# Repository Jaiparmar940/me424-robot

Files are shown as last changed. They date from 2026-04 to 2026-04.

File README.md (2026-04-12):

# ME424 Robot — Multi-Board ESP32 Firmware

Firmware for a 5-DOF robotic arm with an interchangeable tool head system. Three ESP32 dev boards communicate over UART to coordinate stepper motors, limit switches, and tool attachments (electromagnet, vacuum, circular saw, linear probe, etc.).

The wrist uses an 8-pin magnetic connector to hot-swap tools.

## System Architecture

```
┌──────────────┐   UART2    ┌──────────────┐
│              │ ──────────▸│              │
│  Main Board  │            │ MOSFET Board │   (tool power switching)
│              │◂────────── │              │
│              │   115200   └──────────────┘
│              │
│  - Wi‑Fi     │   UART1    ┌──────────────┐
│  - Steppers  │ ──────────▸│              │
│  - Commands  │            │ Sensor Board │   (limit switches, tool ID)
│              │◂────────── │              │
└──────────────┘   115200   └──────────────┘
```

| Board | Role |
|---|---|
| **Main Board** | Master controller. USB serial, Wi‑Fi (HTTP UI + WebSocket + OTA), drives 6 stepper motors via TB6600 drivers, routes commands to other boards over UART. |
| **MOSFET Board** | Receives commands from Main Board over UART. Drives 3 MOSFET outputs for electromagnet, vacuum, and circular saw. Sends ACK responses. |
| **Sensor Board** | Reads three limit switches plus Stage 5 Hall-at-zero (GPIO14 / HW-477) and reports state changes to Main Board over UART. |

## Project Structure

```
ME424_Robot/
├── platformio.ini              Multi-environment build config
├── src/
│   ├── main_board/main.cpp     Main board firmware
│   ├── mosfet_board/main.cpp   MOSFET slave board firmware
│   └── sensor_board/main.cpp   Sensor board firmware
├── include/                    Shared headers (empty, for future use)
├── lib/                        Shared libraries (empty, for future use)
└── .gitignore
```

---

## Pin Assignments

### Main Board

#### Stepper Motor Outputs (to TB6600 drivers)

| Controller | Stage Mapping | STEP Pin | DIR Pin | Direction Inverted |
|---|---|---|---|---|
| 1 | Stage 2 Right | GPIO 25 | GPIO 13 | No |
| 2 | Stage 3 | GPIO 33 | GPIO 14 | No |
| 3 | Stage 4 | GPIO 32 | GPIO 22 | No |
| 4 | Stage 2 Left | GPIO 27 | GPIO 21 | **Yes** |
| 5 | Stage 5 | GPIO 26 | GPIO 23 | No |
| 6 | Stage 1 (turntable) | GPIO 4 | GPIO 15 | No |

Stage 2 uses two motors (controllers 1 and 4) driven in sync. Controller 4 has its direction inverted so both motors move the same physical direction.

#### UART Connections

| Bus | Function | Main Board Pin | Remote Board Pin | Baud |
|---|---|---|---|---|
| UART2 | To MOSFET board | RX = GPIO 16, TX = GPIO 17 | MOSFET RX = GPIO 25, TX = GPIO 26 | 115200 |
| UART1 | To Sensor board | RX = GPIO 18, TX = GPIO 19 | Sensor TX = GPIO 27, RX = GPIO 26 | 115200 |
| UART0 | USB Serial (debug) | Default (GPIO 1 / 3) | — | 115200 |

#### Other

| Function | Details |
|---|---|
| Wi‑Fi | Station mode: OTA updates, HTTP dashboard on port 80, WebSocket commands on 81, optional TCP 3333 |

---

### MOSFET Board

GPIO **18** and **19** are the usual **MOSFET-switched** loads (mag, vac). GPIO **22** is different: it is a **small-signal / PWM line into an external BLDC driver module** (ESC or similar), not a discrete power MOSFET driven directly like 18/19. GPIO **23** enables saw **power** ahead of that driver.

| Function | GPIO | Mode | Notes |
|---|---|---|---|
| Electromagnet output | 18 | OUTPUT | Active HIGH → MOSFET (or equivalent) |
| Vacuum output | 19 | OUTPUT | Active HIGH → MOSFET (or equivalent) |
| Saw power / enable | 23 | OUTPUT | Active HIGH — supply or enable path to the BLDC driver |
| BLDC driver speed input | 22 | LEDC ~5 kHz | PWM duty 0–100% via `SAW SPEED` (driver module input; only while `SAW ON`) |
| UART RX (from Main TX) | 25 | UART1 RX | Cross-wired to Main GPIO 17 |
| UART TX (to Main RX) | 26 | UART1 TX | Cross-wired to Main GPIO 16 |
| USB Serial (debug) | Default | UART0 | 115200 baud |

All outputs default to LOW (off) on boot. The board sends `SLAVE READY` to the main board on startup.

---

### Sensor Board

| Function | GPIO | Mode | Notes |
|---|---|---|---|
| Stage 2 Limit Switch | 33 | INPUT_PULLUP | Active LOW (switch wired to GND) |
| Stage 3 Limit Switch | 32 | INPUT_PULLUP | Active LOW |
| Stage 4 Limit Switch | 25 | INPUT_PULLUP | Active LOW |
| UART TX (to Main RX) | 27 | UART1 TX | Cross-wired to Main GPIO 18 |
| UART RX (from Main TX) | 26 | UART1 RX | Cross-wired to Main GPIO 19 |
| USB Serial (debug) | Default | UART0 | 115200 baud |

---

## UART Wiring Diagram

```
Main Board                    MOSFET Board
──────────                    ────────────
GPIO 16 (RX2)  ◂──────────  GPIO 26 (TX1)
GPIO 17 (TX2)  ──────────▸  GPIO 25 (RX1)
GND            ──────────── GND

Main Board                    Sensor Board
──────────                    ────────────
GPIO 18 (RX1)  ◂──────────  GPIO 27 (TX1)
GPIO 19 (TX1)  ──────────▸  GPIO 26 (RX1)
GND            ──────────── GND
```

All UART buses run at **115200 baud, 8N1**.

---

## Command Reference

Commands are sent to the Main Board over **USB serial**, **WebSocket** (same line protocol as serial), or **TCP 3333**. Each command is case-insensitive and terminated by a newline (`\n`). Responses are echoed to USB and any active network clients.

### Stage Commands

| Command | Description |
|---|---|
| `s1cw <steps>` | Stage 1 (turntable) clockwise |
| `s1ccw <steps>` | Stage 1 (turntable) counter-clockwise |
| `s2up <steps>` | Stage 2 up (controllers 1 + 4 in sync, forward) |
| `s2down <steps>` | Stage 2 down (controllers 1 + 4 in sync, reverse) |
| `s3up <steps>` | Stage 3 up |
| `s3down <steps>` | Stage 3 down |
| `s4up <steps>` | Stage 4 up |
| `s4down <steps>` | Stage 4 down |
| `s5cw <steps>` | Stage 5 clockwise |
| `s5ccw <steps>` | Stage 5 counter-clockwise |

### Raw Controller Commands

| Command | Description |
|---|---|
| `c1f <steps>` / `c1r <steps>` | Controller 1 forward / reverse (Stage 2 Right) |
| `c2f <steps>` / `c2r <steps>` | Controller 2 forward / reverse (Stage 3) |
| `c3f <steps>` / `c3r <steps>` | Controller 3 forward / reverse (Stage 4) |
| `c4f <steps>` / `c4r <steps>` | Controller 4 forward / reverse (Stage 2 Left) |
| `c5f <steps>` / `c5r <steps>` | Controller 5 forward / reverse (Stage 5) |
| `c6f <steps>` / `c6r <steps>` | Controller 6 forward / reverse (Stage 1 / turntable) |

### MOSFET / Tool Commands

These are forwarded from the Main Board to the MOSFET Board over UART.

| Command | Forwarded As | MOSFET Board Response |
|---|---|---|
| `mag on` / `mag off` | `MAG ON` / `MAG OFF` | `ACK MAG ON` / `ACK MAG OFF` |
| `vac on` / `vac off` | `VAC ON` / `VAC OFF` | `ACK VAC ON` / `ACK VAC OFF` |
| `saw on` / `saw off` | `SAW ON` / `SAW OFF` | `ACK SAW ON` / `ACK SAW OFF` |
| `saw speed <0–100>` | `SAW SPEED <n>` | `ACK SAW SPEED <n>` — PWM on MOSFET **GPIO 22** while saw is on |
| `alloff` | `ALL OFF` | `ACK ALL OFF` |
| `mstatus` | `STATUS` | `STATUS … SAW_SPD=<0–100> …` |

### Sequence Commands

Commands are separated by `,`. Whitespace around commas is ignored.

| Command | Description |
|---|---|
| `seq <cmd1>, <cmd2>, ...` | Execute commands one at a time in order. Any command type is valid (motor, MOSFET, utility). |
| `par <cmd1>, <cmd2>, ...` | Execute motor commands simultaneously. All specified motors are stepped on the same clock tick. Motor/stage commands only — MOSFET commands are not supported in `par`. |
| `syncabs t1 t2 t3 t4 t5 t6 maxSps rampSteps` | Execute a synchronized **absolute** 6-axis move. Each axis reaches its target at the same time, speed is capped by `maxSps` (steps/s), and accel/decel ramping is applied using `rampSteps`. |
| `vertical [maxSps] [ramp]` | Same as the web **Go to vertical** button: `syncabs` to the stored vertical pose (defaults **1200** / **150**). Targets live in firmware as `kAppVerticalPose` — keep in sync with `VERTICAL_POSE` in `app.js`. |
| `autohome [maxSps] [ramp]` | Same as the web **Lift autohome** button: full lift calibration, ending at vertical then `setpos` all zeros. Optional `maxSps` / `ramp` override defaults **1200** / **150**. Constants match `LIFT_ROUTINE` in `app.js`. |
| `qclear` | Clear onboard queue |
| `qadd pose t1 t2 t3 t4 t5 t6 maxSps rampSteps` | Append a synchronized absolute move segment to onboard queue |
| `qadd delay ms` | Append delay segment to onboard queue |
| `qadd cmd <firmware command>` | Append command segment (e.g. `vac on`, `alloff`) |
| `qlist` | Print current queue items |
| `qrun` | Execute queued items on firmware (true onboard playlist execution) |
| `qstop` | Request stop for running queue |
| `qstatus` | Print queue count and stop state |

**Examples:**
```
seq s2up 400, s3down 200, mag on
par s2up 400, s5cw 200
par s3down 200, s4down 300, s1cw 100
seq par s3down 400, s4down 400, s2up 200, mag on
syncabs 0 1000 -500 0 200 0 1200 300
qclear
qadd pose 0 400 0 0 0 0 900 150
qadd delay 500
qadd cmd vac on
qadd pose 0 0 0 0 0 0 900 150
qadd cmd vac off
qrun
```

In `par`, motors with different step counts run until each individually finishes — longer moves continue while shorter ones stop. Limits are checked per-motor on every step.

### Utility Commands

| Command | Description |
|---|---|
| `speed <us>` | Set stepper pulse delay in microseconds (minimum 100) |
| `where` | Print the tracked current position for all 6 controllers |
| `setpos p1 p2 p3 p4 p5 p6` | Overwrite the tracked position state (useful after manual zeroing/homing) |
| `estop` | Latch emergency stop immediately (also during active motion/queue). Motion commands are blocked until cleared. Also sends `ALL OFF` to MOSFET board. |
| `estop clear` | Clear the e-stop latch to allow motion again |
| `estop status` | Print `ESTOP=1` or `ESTOP=0` |
| `limits` | Print last-known limit switch and Stage 5 Hall (`S5H`) states |
| `home s1` | Jog turntable (C6) in the + direction (`c6f` / `s1cw`) until the S1 CW limit is active, then set C6 to 0. Uses a **slower** step pulse during the seek than global `speed` (≈2× delay, capped) so the table homes gently. |
| `home s2` | Drive Stage 2 toward its limit, then zero C1/C4 at the limit |
| `home s3` | Drive Stage 3 toward its limit, then zero C2 |
| `home s4` | Drive Stage 4 toward its limit, then zero C3 |
| `home s5` | Jog Stage 5 until Hall at zero (`S5H=0`), then zero C5 |
| `home s1 bounce` … `home s4 bounce` | Same as `home sN` but: fast approach, back off 260 steps, slow final creep, then zero. **S1 (turntable)** uses **slower** fast/slow pulse scaling than S2–S4 (see firmware `homeS1Bounce*PulseUs`). Stage 5 has no bounce variant. |
| `help` | Print command menu |

---

## Limit Switch Safety

The sensor board monitors three limit switches plus a Stage 5 Hall line (3144-style sensor through an HW-477 comparator on **GPIO14**; homing-only, not a motion limit) and sends state changes to the main board using this protocol:

```
LIM S2=1 S3=0 S4=0 S5H=0
```

For **S2–S4**, `1` = limit switch triggered (pressed), `0` = open. For **S5H** the convention is reversed: **`0` = at Hall zero position**, `1` = away from zero. Adjust the HW-477 threshold pot. Sensor firmware defaults to **`S5_HALL_AT_ZERO_ACTIVE_HIGH = false`** (pin **LOW** = at zero); set to `true` if your comparator output is the opposite.

### Behavior

The main board uses direction-aware limit logic. Limits only block motion in the **downward** direction for a given stage — upward motion is always allowed even if the limit is triggered. The sensor UART is polled mid-step so limits are checked during long moves and will halt motion immediately.

If a limit is already active when a command is received, the command is rejected with an `ABORT` message. If a limit triggers mid-move, the motors stop and a `STOP` message is sent.

### Direction Mapping

| Stage | "Down" Direction | Limit Blocks |
|---|---|---|
| Stage 1 | — | No limit switch |
| Stage 2 | `s2down` (forward = false) | Downward motion only |
| Stage 3 | `s3down` (forward = true) | Downward motion only |
| Stage 4 | `s4down` (forward = true) | Downward motion only |
| Stage 5 | — | No limit switch (Hall `S5H` on sensor board is for **homing only**, not blocking motion) |

### Limit-to-Motor Mapping

| Limit Switch | Motors Affected |
|---|---|
| Stage 2 | Controllers 1 + 4 (stopped together) |
| Stage 3 | Controller 2 |
| Stage 4 | Controller 3 |

---

## Wi‑Fi usage (replaces Bluetooth)

Bluetooth Classic has been removed to save flash/RAM. Use one of the following:

| Channel | Purpose |
|---|---|
| USB serial | 115200 baud, same as before |
| Browser | Open `http://me424-main.local/` (or the main board IP) for the hosted web app; it connects over WebSocket port 81 |
| TCP | `nc me424-main.local 3333` for raw line commands |
| OTA | PlatformIO `*_ota` environments upload firmware over the network |

### Serial terminal settings (USB)

| Setting | Value |
|---|---|
| Baud rate | 115200 |
| Data bits | 8 |
| Parity | None |
| Stop bits | 1 |
| Line ending | Newline (`\n`) |

---

## Tool Connector (8-Pin Magnetic)

The wrist connector carries power and signals to interchangeable tools:

| Pin(s) | Function | Direction | Notes |
|---|---|---|---|
| 1, 2 | V+ (tool power) | Arm -> Tool | Paralleled for current capacity |
| 3, 4 | GND | — | Paralleled |
| 5 | BLDC PWM control | Arm -> Tool | PWM signal to on-tool motor driver |
| 6 | BLDC enable / digital control | Arm -> Tool | Enable line |
| 7 | ADC signal (shared) | Tool -> Arm | Probe potentiometer OR tool ID resistor |
| 8 | Spare | — | Reserved for future use |

### Tool Identification

Each tool contains a resistor to GND on pin 7. The arm has a fixed pull-up resistor to 3.3V on the same pin, forming a voltage divider read by the sensor board's ADC. Different resistance values identify different tools.

```
3.3V ── [fixed R on board] ──┬── ADC pin (GPIO on sensor board)
                              │
                    [tool R] ── GND (through connector)
```

> Tool ID and ADC reading are not yet implemented in firmware.

---

## Building and Uploading

### Prerequisites

- [PlatformIO IDE extension](https://platformio.org/install/ide?install=vscode) installed in VS Code / Cursor
- ESP32 USB drivers installed (CP2102 or CH340 depending on your dev board)

### Using the PlatformIO IDE (recommended)

1. Open the `ME424_Robot` folder in Cursor/VS Code.
2. PlatformIO will auto-detect `platformio.ini` and index the project.
3. Use the PlatformIO sidebar or the bottom toolbar:
   - Click the **environment switcher** in the status bar to select `main_board`, `mosfet_board`, or `sensor_board`.
   - Click **Build** (checkmark icon) to compile.
   - Click **Upload** (arrow icon) to flash the selected board.
   - Click **Serial Monitor** (plug icon) to open the monitor at 115200 baud.

### Using the PlatformIO CLI

```bash
# Build a specific board
pio run -e main_board
pio run -e mosfet_board
pio run -e sensor_board

# Upload to a specific board (auto-detects USB port)
pio run -e main_board -t upload
pio run -e mosfet_board -t upload
pio run -e sensor_board -t upload

# Upload to a specific USB port
pio run -e main_board -t upload --upload-port /dev/cu.usbserial-0001

# Open serial monitor
pio device monitor -e main_board

# Build all environments
pio run

# Clean build artifacts
pio run -t clean
```

### WiFi / OTA Upload (All Boards)

Bluetooth transport on the main board has been replaced with WiFi command + OTA support.  
All three boards now support Arduino OTA when WiFi credentials are compiled in.

1. Set WiFi credentials in `platformio.ini` under `[env]` (`build_flags`: `WIFI_SSID`, `WIFI_PASSWORD`). Each board env merges these via `${env.build_flags}`.
2. First flash each board once over USB:

```bash
pio run -e main_board -t upload
pio run -e mosfet_board -t upload
pio run -e sensor_board -t upload
```

3. Then use OTA environments:

```bash
pio run -e main_board_ota -t upload
pio run -e mosfet_board_ota -t upload
pio run -e sensor_board_ota -t upload
```

Default OTA hostnames are:
- `me424-main.local`
- `me424-mosfet.local`
- `me424-sensor.local`

### Wireless web app (main board)

The main board serves the dashboard from **LittleFS** at **`http://<ip>/`** (try `http://me424-main.local/`). The same UI talks to the firmware over **WebSocket** port **81** (line-based commands, same as USB serial). Raw TCP on port **3333** still works for `nc` / scripts.

After changing files in `app/`, copy them into `data/` and upload the filesystem (USB or OTA):

```bash
cp app/index.html app/app.js app/styles.css data/
pio run -e main_board -t uploadfs
# or, after OTA works:
pio run -e main_board_ota -t uploadfs
```

Open the UI in a browser on the same Wi‑Fi network; the page auto-connects over Web‑Fi. Use `http://localhost:8080/app/` (or similar) with **Connect (USB Serial)** for local dev, or add **`?usb=1`** to the robot URL to force USB from a desktop.

### Setting Upload Ports

If you have multiple ESP32 boards connected simultaneously, uncomment and set the `upload_port` lines in `platformio.ini`:

```ini
[env:main_board]
build_src_filter = -<*> +<main_board/>
upload_port = /dev/cu.usbserial-0001

[env:mosfet_board]
build_src_filter = -<*> +<mosfet_board/>
upload_port = /dev/cu.usbserial-0002

[env:sensor_board]
build_src_filter = -<*> +<sensor_board/>
upload_port = /dev/cu.usbserial-0003
```

To find your port names:

```bash
# macOS / Linux
ls /dev/cu.usb*

# Windows (in PlatformIO terminal)
pio device list
```

### Upload Order

There is no strict order, but a practical sequence is:

1. **Sensor board** — starts reporting limits immediately on boot
2. **MOSFET board** — starts listening for commands, all outputs default off
3. **Main board** — expects the other two boards to already be running

---

## Web App (8 Requirements UI)

A browser app is included at `app/` and uses Web Serial to talk directly to the main ESP.

### Run the App

1. Start a local static server from repo root:
   - `python3 -m http.server 8080`
2. Open [http://localhost:8080/app/](http://localhost:8080/app/)
3. Click **Connect (Web Serial)** and select your ESP32 serial port.

Use Chrome or Edge desktop (Web Serial is not supported in Safari/Firefox).

### Requirement Coverage

1. **Manual jog with granularity**
   - `Manual Control` section
   - Set `Step Size`
   - Use `+ Jog` / `- Jog` per motor

2. **Record all 6 positions in one state**
   - `Record Current Pose` captures all 6 tracked positions

3. **Add delays between states**
   - Set `Delay (ms)` and click `Add Delay`

4. **Append more recorded positions**
   - Record additional poses; list appends in order

5. **Toggle MOSFET functions in same list**
   - Choose `MOSFET Action`, click `Add MOSFET Action`

6. **Replay with synchronized finish + ramps + max speed**
   - Sequence playback uses firmware command:
     - `syncabs t1 t2 t3 t4 t5 t6 maxSps rampSteps`
   - `Playback maxSps` and `Playback rampSteps` control speed/ramp
   - Axis motion is synchronized so all active axes finish together

7. **Zero / home from buttons**
   - `Set Current as Zero (All)` → soft-zero all tracked positions (`setpos …`)
   - `Zero This Axis` on each axis → soft-zero that controller only
   - `Auto home (home sN)` under each stage → runs the matching firmware homing command (`home s1` … `home s5`)
   - `Home Stages 2–4 (limits)` → runs `home s2`, then `home s3`, then `home s4` in order

8. **Save commands locally**
   - `Save Local` / `Load Local` uses browser `localStorage`
   - `Export JSON` / `Import JSON` for file-based reuse

### App Data Model

Sequence items are one of:
- `pose`: six-axis absolute positions
- `delay`: milliseconds
- `mosfet`: command string (`mag on`, `vac off`, etc.)

---

## Inter-Board Protocols

### Sensor Board (Sensor <-> Main)

#### Messages Sent (Sensor -> Main)

| Message | Meaning |
|---|---|
| `SENSOR READY` | Boot complete |
| `LIM S2=<0\|1> S3=<0\|1> S4=<0\|1> S5H=<0\|1>` | S2–S4: `1` = limit hit; **S5H: `0` = at Hall zero**, `1` = away (sent on change and at boot) |
| `ERR UNKNOWN_CMD` | Unrecognized command received |

#### Commands Accepted (Main -> Sensor)

| Command | Response |
|---|---|
| `STATUS` | Sends current `LIM ...` message |

### MOSFET Board (MOSFET <-> Main)

#### Messages Sent (MOSFET -> Main)

| Message | Meaning |
|---|---|
| `SLAVE READY` | Boot complete |
| `ACK MAG ON` / `ACK MAG OFF` | Electromagnet toggled |
| `ACK VAC ON` / `ACK VAC OFF` | Vacuum toggled |
| `ACK SAW ON` / `ACK SAW OFF` | Saw toggled |
| `ACK ALL OFF` | All outputs turned off |
| `STATUS … SAW_SPD=<0–100> …` | Current outputs + saw PWM setpoint |
| `ERR UNKNOWN_CMD` | Unrecognized command received |

#### Commands Accepted (Main -> MOSFET)

| Command | Response |
|---|---|
| `MAG ON` / `MAG OFF` | `ACK MAG ON` / `ACK MAG OFF` |
| `VAC ON` / `VAC OFF` | `ACK VAC ON` / `ACK VAC OFF` |
| `SAW ON` / `SAW OFF` | `ACK SAW ON` / `ACK SAW OFF` |
| `ALL OFF` | `ACK ALL OFF` |
| `STATUS` | `STATUS MAG=... VAC=... SAW=... SAW_SPD=... TOOL_R=...` |

---

## Future Work

- [ ] Add tool identification via ADC voltage divider on the sensor board
- [ ] Add linear probe (potentiometer) reading
- [ ] Add debouncing / filtering to limit switch reads
- [ ] Add shared protocol header in `lib/` for message definitions

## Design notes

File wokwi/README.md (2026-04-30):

# ME424 Wokwi Circuit Model

This folder contains a Wokwi-importable visual wiring model for your control circuit:

- `diagram.json`

## What this model includes

- Main ESP32 (`main`) and Sensor ESP32 (`sensor`)
- UART link between boards (GPIO19/18 pair represented via UART1 TX/RX symbols)
- Sensor limit inputs:
  - Stage 1 CW limit -> GPIO13
  - Stage 2 limit -> GPIO33
  - Stage 3 limit -> GPIO32
  - Stage 4 limit -> GPIO25
  - Stage 5 Hall input -> GPIO14
- Tool outputs on sensor board:
  - MAG -> GPIO18
  - VAC -> GPIO19
  - SAW MOSFET gate -> GPIO21
  - SAW PWM -> GPIO22
- Tool ID / probe analog model:
  - ADC34 with 10k divider + tool resistor
  - ADC35 shown tied to a potentiometer signal
- Main board motor control indicators:
  - STEP pins: 25, 33, 32, 27, 26, 4
  - DIR pins: 13, 14, 22, 21, 23, 15

## Upload / open online

1. Go to [Wokwi ESP32 New Project](https://wokwi.com/projects/new/esp32).
2. Open `diagram.json` in this folder.
3. Copy all content and paste it into Wokwi's `diagram.json`.
4. Click **Save**.

## Notes

- This is a **visual/logic wiring model** for documentation and interaction testing.
- It is not an exact electrical model of TB6600 drivers, power rails, or saw power electronics.
- If you want, I can generate a second version with:
  - explicit virtual buttons for common commands,
  - a clearer grouped layout for screenshots,
  - or a dedicated variant matching `main_board_sensor_mosfet`.

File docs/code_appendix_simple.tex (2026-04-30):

% =====================================================
% ME424 Robot - SIMPLE TIGHT CODE APPENDIX
% =====================================================
% 
% Add to the VERY FIRST LINE of main.tex:
% \UseRawInputEncoding
% 
% Add to preamble:
% \usepackage{verbatim}
% \usepackage{xcolor}
% \usepackage{hyperref}
% 
% Usage:
% \input{code/docs/code_appendix_simple.tex}
% (or paste the content below directly into your appendix section)

\section*{Appendix: Complete Project Source Code}
\label{app:full-source}
\addcontentsline{toc}{section}{Appendix: Complete Project Source Code}

This appendix contains all custom project code with very tight formatting (\scriptsize font, minimal spacing). Only project-specific files are included.

\subsection*{Firmware - Main Board}

\textbf{File: \texttt{code/src/main\_board/main.cpp} (Primary implementation)}

\verbatiminput{code/src/main_board/main.cpp}

\textbf{File: \texttt{code/main\_board/main\_board.ino} (Legacy)}

\verbatiminput{code/main_board/main_board.ino}

\subsection*{Firmware - Sensor Board}

\textbf{File: \texttt{code/sensor\_board/sensor\_board.ino}}

\verbatiminput{code/sensor_board/sensor_board.ino}

\textbf{File: \texttt{code/src/sensor\_board/main.cpp}}

\verbatiminput{code/src/sensor_board/main.cpp}

\subsection*{Firmware - MOSFET/Tool Board}

\textbf{File: \texttt{code/src/mosfet\_board/main.cpp}}

\verbatiminput{code/src/mosfet_board/main.cpp}

\textbf{File: \texttt{code/mosfet\_board/mosfet\_board.ino}}

\verbatiminput{code/mosfet_board/mosfet_board.ino}

\subsection*{Web Interface}

\textbf{File: \texttt{code/app/app.js} (Main UI)}

\verbatiminput{code/app/app.js}

\textbf{File: \texttt{code/data/app.js}}

\verbatiminput{code/data/app.js}

\subsection*{Configuration \& Docs}

\textbf{File: \texttt{code/platformio.ini}}

\verbatiminput{code/platformio.ini}

\textbf{File: \texttt{code/README.md}}

\verbatiminput{code/README.md}

\textbf{File: \texttt{code/wokwi/diagram.json}}

\verbatiminput{code/wokwi/diagram.json}

\textbf{File: \texttt{code/docs/application_ui_subsection.tex}}

\verbatiminput{code/docs/application_ui_subsection.tex}

\subsection*{ROS/Python Support (Key Files)}

\textbf{File: \texttt{code/ros-py/serial_bridge.py}}

\verbatiminput{code/ros-py/serial_bridge.py}

\textbf{File: \texttt{code/ros-py/ros_src.py}}

\verbatiminput{code/ros-py/ros_src.py}

\subsection*{Pose Data Example}

\textbf{File: \texttt{code/poses/me424-homing.json}}

\verbatiminput{code/poses/me424-homing.json}

\vspace{0.5em}
\noindent \textbf{Note:} Very tight formatting with \scriptsize font and minimal spacing. If any file is not found, upload the `code/` folder structure to Overleaf or comment out the line with \%. 

To reference this appendix: `\ref{app:full-source}` or `\autoref{app:full-source}`.

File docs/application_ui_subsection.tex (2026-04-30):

\subsection{Application and User Interface Functionality}
\label{subsec:application-ui-functionality}

The ME424 robot application provides a browser-based operator interface that connects to the main controller over Wi-Fi and supports both low-level actuator control and higher-level task execution. At runtime, the firmware serves a web interface from onboard flash storage (LittleFS), accepts commands through WebSocket/TCP channels, and relays status from both the motion controller and the sensor/tool subsystem. This design gives users a single interface for motion, homing, tooling, safety control, and system diagnostics.

\subsubsection{Overall UI Structure and Operator Workflow}

The UI is organized to support a practical workflow:
\begin{enumerate}
  \item Connect to the robot over the network and confirm communication.
  \item Inspect robot state (positions, limits, and tool status).
  \item Home required stages to establish a known reference.
  \item Execute manual jog commands or synchronized/queued routines.
  \item Enable or disable end-effector tools as needed.
  \item Monitor acknowledgements, errors, and safety events in real time.
\end{enumerate}

In normal operation, the interface acts as a command console with structured controls, while the firmware enforces hardware safety constraints (limit blocking and e-stop latching) in the background.

\begin{figure}[htbp]
  \centering
  % Replace the file name with your screenshot path
  
  \caption{Main web UI overview, showing command controls, status panels, and live output.}
  \label{fig:ui-overview}
\end{figure}

\subsubsection{Connection, Session Feedback, and Live Communication}

When loaded in a browser, the UI establishes a live command/status channel to the main board (WebSocket on port 81, with TCP command support on port 3333). The interface should indicate connection state and then begin displaying streamed acknowledgements and state lines. Typical operator-visible feedback includes:
\begin{itemize}
  \item \texttt{ACK ...} messages confirming accepted commands,
  \item \texttt{DONE ...} messages when motions complete,
  \item \texttt{ERR ...} messages for malformed or invalid requests,
  \item limit and sensor reports relayed from the sensor board,
  \item emergency-stop state transitions (\texttt{ESTOP LATCHED/CLEARED}).
\end{itemize}

This continuous feedback loop is critical: users should interpret the UI as a command-and-confirm system rather than a fire-and-forget interface.

\begin{figure}[htbp]
  \centering
  
  \caption{Connection and live status area showing command acknowledgements and device responses.}
  \label{fig:ui-connection-status}
\end{figure}

\subsubsection{Manual Motion Controls and Direct Interaction}

The interface supports direct motion through stage-based controls and raw controller commands:
\begin{itemize}
  \item Stage commands (\texttt{s1cw}, \texttt{s2up}, \texttt{s3down}, etc.) provide semantically meaningful robot actions.
  \item Raw controller commands (\texttt{cXf}/\texttt{cXr}) expose per-driver step control for debugging and calibration.
  \item Adjustable speed/timing parameters allow users to tune responsiveness and smoothness.
\end{itemize}

User interaction is typically button-driven (for common motions) or text-command-driven (for advanced commands). The system validates step counts and rejects invalid values. During motion, the firmware monitors limits and e-stop state every cycle; if a stop condition is encountered, motion is aborted and the event is reported back to the UI.

\begin{figure}[htbp]
  \centering
  
  \caption{Manual motion controls for stage-level and controller-level movement commands.}
  \label{fig:ui-manual-motion}
\end{figure}

\subsubsection{Homing and Coordinate Management Features}

A key UI feature is guided homing and zero management. The operator can issue homing commands per stage:
\begin{itemize}
  \item Stage 1 homes to a clockwise limit reference.
  \item Stages 2--4 home to mechanical limit switches with direction-aware blocking.
  \item Stage 5 homes to a Hall-sensor zero region.
  \item Bounce homing modes improve repeatability by using a two-pass touch strategy.
\end{itemize}

The application also supports tracked position display (\texttt{where}), direct position overwrite (\texttt{setpos}), and persistent zero-step offsets by stage. This makes the UI suitable for both everyday operation and setup/recalibration sessions.

\begin{figure}[htbp]
  \centering
  
  \caption{Homing and position-management controls, including zeroing workflow and state readback.}
  \label{fig:ui-homing-position}
\end{figure}

\subsubsection{Sequencing, Queues, and Coordinated Task Execution}

Beyond manual control, the UI exposes multiple routine-execution mechanisms:
\begin{itemize}
  \item \textbf{Sequential execution} (\texttt{seq}): runs a comma-separated list of commands in order.
  \item \textbf{Parallel execution} (\texttt{par}): runs supported motor commands simultaneously.
  \item \textbf{Synchronized absolute motion} (\texttt{syncabs}): executes multi-axis targets with speed and ramp limits.
  \item \textbf{Queue manager}: supports \texttt{qadd pose}, \texttt{qadd delay}, \texttt{qadd cmd}, \texttt{qlist}, \texttt{qrun}, \texttt{qstop}, and \texttt{qclear}.
\end{itemize}

From a user perspective, this enables a progression from manual jogs to repeatable scripted workflows. The queue panel should be documented with expected operator steps: construct queue, verify items, execute, monitor logs, and stop/clear if needed.

\begin{figure}[htbp]
  \centering
  
  \caption{Queue and routine execution controls for repeatable multi-step operation.}
  \label{fig:ui-queue-routines}
\end{figure}

\subsubsection{Tooling Panel and End-Effector Interaction}

The UI includes dedicated controls for end-effector tooling:
\begin{itemize}
  \item magnet control (\texttt{MAG ON/OFF}),
  \item vacuum control (\texttt{VAC ON/OFF}),
  \item saw enable/disable (\texttt{SAW ON/OFF}),
  \item saw speed command (\texttt{SAW SPEED x}),
  \item global tool shutdown (\texttt{ALL OFF}),
  \item tool telemetry query (\texttt{MSTATUS}).
\end{itemize}

Returned tool telemetry includes actuator states, saw speed setpoint, identified tool resistor class, and compression/probe displacement estimate. This gives users immediate confirmation that the expected attachment is detected and that commanded tool states are active.

\begin{figure}[htbp]
  \centering
  
  \caption{Tooling controls and status readback for magnet, vacuum, and saw subsystems.}
  \label{fig:ui-tooling-panel}
\end{figure}

\subsubsection{Safety, Fault Handling, and Operator Responsibilities}

The UI exposes safety commands directly, but safety enforcement is implemented in firmware:
\begin{itemize}
  \item Emergency stop can be latched from serial or network sources.
  \item While latched, all commanded motion is blocked.
  \item Tool outputs are forced off on e-stop latch via \texttt{ALL OFF}.
  \item Limit-switch and Hall-derived states are continuously integrated into command blocking logic.
\end{itemize}

Recommended user interaction pattern:
\begin{enumerate}
  \item Before motion: check limit and e-stop status.
  \item During motion: watch live acknowledgements and stop on unexpected behavior.
  \item Before tool activation: verify tool identification/status panel.
  \item After operation: use \texttt{ALL OFF} and confirm final system state.
\end{enumerate}

\begin{figure}[htbp]
  \centering
  
  \caption{Safety and fault status region with e-stop state and limit feedback.}
  \label{fig:ui-safety-status}
\end{figure}

\subsubsection{How to Integrate This Section in a Report}

This file is intended to be included from a larger report using:
\begin{verbatim}
\input{docs/application_ui_subsection.tex}
\end{verbatim}

To compile successfully, ensure your preamble includes:
\begin{verbatim}
\usepackage{graphicx}
\end{verbatim}

Then add the corresponding screenshot image files under a directory such as \texttt{figures/}, matching the filenames used in the \texttt{\textbackslash includegraphics} commands.

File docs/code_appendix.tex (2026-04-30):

% =====================================================
% ME424 Robot Project - Complete Code Appendix (Overleaf - code/ folder)
% =====================================================
%
% **Your structure**: All folders are inside a top-level `code/` folder.
% Paths have been updated to `code/src/...`, `code/app/...`, etc.
%
% **Simplest option (recommended)**:
% 1. Copy-paste the content below (starting at \section*{Appendix...}) into your main report's appendix.
% 2. Ensure the `code/` folder exists in Overleaf with all the subfolders/files.
% 3. Add these packages to your main report preamble (near the top):
%      \usepackage[utf8]{inputenc}
%      \usepackage[T1]{fontenc}
%      \usepackage{listings}
%      \usepackage{xcolor}
%      \usepackage{hyperref}
%      \usepackage{array}   % fixes the "Illegal pream-token (L/C)" table errors
% 4. Recompile. The new settings should resolve the UTF-8, JavaScript, and math-mode errors.
%
% If you still get errors, reply with the new log — common fixes are ready.

\lstset{
  basicstyle=\ttfamily\scriptsize,
  keywordstyle=\color{blue}\bfseries,
  commentstyle=\color{green!60!black},
  stringstyle=\color{red!60!black},
  numberstyle=\tiny\color{gray!60},
  numbersep=4pt,
  backgroundcolor=\color{gray!8},
  frame=single,
  framesep=3pt,
  framerule=0.4pt,
  tabsize=2,
  breaklines=true,
  breakatwhitespace=true,
  postbreak=\mbox{\textcolor{red}{$\hookrightarrow$}\space},
  keepspaces=true,
  showspaces=false,
  showstringspaces=false,
  aboveskip=2pt,
  belowskip=2pt,
  xleftmargin=12pt,
  xrightmargin=6pt,
  columns=flexible,
  linewidth=0.98\linewidth,
  inputencoding=utf8,
  extendedchars=true,
  % Prevent UTF-8 and special character errors common in Arduino/JS code
  literate={�}{{\textquestiondown}}1 {–}{{-}}1 {’}{{'}}1 {“}{{"}}1 {”}{{"}}1,
  % Make JavaScript use C++ highlighting (more reliable in listings)
  language=C++
}

% Define additional languages
\lstdefinelanguage{PlatformIO}{
  morekeywords={platform,board,framework,env,build_flags,lib_deps,build_src_filter,upload_port,monitor_speed,upload_protocol,extends},
  sensitive=false,
  morecomment=[l]{;},
  morecomment=[l]{\#},
}

% For Markdown and JSON, listings falls back gracefully

\section*{Appendix: Complete Project Source Code}

\subsection*{Firmware - Main Board}
\textbf{File:} \texttt{src/main_board/main.cpp} (Primary implementation, \textasciitilde 4100 lines)

\lstinputlisting[language=C++,caption={Primary Main Board Firmware - code/src/main_board/main.cpp},label=lst:src-main-board]{code/src/main_board/main.cpp}

\textbf{File:} \texttt{code/main_board/main_board.ino} (Legacy version)

\lstinputlisting[language=C++,caption={Legacy Main Board - code/main_board/main_board.ino},label=lst:main-board-ino]{code/main_board/main_board.ino}

\subsection*{Firmware - Sensor Board}
\textbf{File:} \texttt{code/sensor_board/sensor_board.ino} (Primary sensor/tool firmware)

\lstinputlisting[language=C++,caption={Sensor Board Firmware - code/sensor_board/sensor_board.ino},label=lst:sensor-board]{code/sensor_board/sensor_board.ino}

\textbf{File:} \texttt{code/src/sensor_board/main.cpp} (PlatformIO version)

\lstinputlisting[language=C++,caption={PlatformIO Sensor Board - code/src/sensor_board/main.cpp},label=lst:src-sensor-board]{code/src/sensor_board/main.cpp}

\subsection*{Firmware - MOSFET/Tool Board}
\textbf{File:} \texttt{code/src/mosfet_board/main.cpp} 

\lstinputlisting[language=C++,caption={MOSFET Board Firmware - code/src/mosfet_board/main.cpp},label=lst:src-mosfet-board]{code/src/mosfet_board/main.cpp}

\textbf{File:} \texttt{code/mosfet_board/mosfet_board.ino} (Legacy)

\lstinputlisting[language=C++,caption={Legacy MOSFET Board - code/mosfet_board/mosfet_board.ino},label=lst:mosfet-board-ino]{code/mosfet_board/mosfet_board.ino}

\subsection*{Web Interface}
\textbf{File:} \texttt{code/app/app.js} (Main browser UI application, \textasciitilde 1565 lines - WebSocket, command UI, pose execution, etc.)

\lstinputlisting[language=C++,caption={Web UI - code/app/app.js},label=lst:app-js]{code/app/app.js}

\textbf{File:} \texttt{code/data/app.js} (Version served from LittleFS)

\lstinputlisting[language=C++,caption={Served UI - code/data/app.js},label=lst:data-app-js]{code/data/app.js}

\subsection*{Project Configuration}
\textbf{File:} \texttt{code/platformio.ini}

\lstinputlisting[language=PlatformIO,caption={PlatformIO Configuration},label=lst:platformio-ini]{code/platformio.ini}

\textbf{File:} \texttt{code/README.md}

\lstinputlisting[language=,caption={Project README.md},label=lst:readme]{code/README.md}

\subsection*{Simulation and Docs}
\textbf{File:} \texttt{code/wokwi/diagram.json} \& \texttt{code/wokwi/README.md}

\lstinputlisting[language=JSON,caption={Wokwi Diagram - code/wokwi/diagram.json},label=lst:wokwi-diagram]{code/wokwi/diagram.json}

\lstinputlisting[language=,caption={Wokwi README},label=lst:wokwi-readme]{code/wokwi/README.md}

\textbf{File:} \texttt{code/docs/application_ui_subsection.tex} (UI documentation subsection)

\lstinputlisting[language=TeX,caption={UI Documentation Subsection},label=lst:ui-subsection]{code/docs/application_ui_subsection.tex}

\subsection*{ROS/Python Support}
Key files from \texttt{ros-py/} (full directory contains additional bridge, IK, launch files; old/ directory has legacy code):

\lstinputlisting[language=Python,caption={Serial Bridge - code/ros-py/serial_bridge.py},label=lst:serial-bridge]{code/ros-py/serial_bridge.py}

\lstinputlisting[language=Python,caption={ROS Source - code/ros-py/ros_src.py},label=lst:ros-src]{code/ros-py/ros_src.py}

% Example of additional files (uncomment and adjust paths as needed):
% \lstinputlisting[language=Python,caption={RAMSES Robot Bridge},label=lst:ramses-bridge]{code/ros-py/ros_def/ramses_robot_bridge/ramses_robot_bridge/ramses_robot_bridge.py}

\subsection*{Pose Data (Example)}
Pose JSON files define motion sequences. Example shown; others follow similar format.

\lstinputlisting[language=JSON,caption={Example Pose - code/poses/me424-homing.json},label=lst:homing-json]{code/poses/me424-homing.json}

% Additional poses (me424-*.json, saw-*.json) can be added similarly if required for the report.

\vspace{1em}
\noindent \textbf{Note:} To generate a fully self-contained version with all code embedded (no \texttt{lstinputlisting}), or to include more ROS files / all poses, reply with specific instructions. The current setup prioritizes practicality for a printed report while satisfying the requirement of having all project code available in one LaTeX reference document. 

The modified \texttt{src/main_board/main.cpp} is fully captured above.

% End of appendix content. Do NOT include \end{document} if you \input this file into a larger report.

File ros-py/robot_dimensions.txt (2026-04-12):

Global Origin (0, 0, 0): at the center of the turntable (x, y), and the height of the the top surface of the docking station (z)
The axis pointing from the turntable out towards the docking station is the positive x-axis.

This means the attachment docking stations have the following coordinates, in inches:
   1. Probe: (9.515, 4.434, 0.0)
   2. Bonesaw: (10.5, 0.0, 0.0)
   3. Vaccuum: (9.515, -4.434, 0.0)

Regarding the links - Consider S1 through S5 as the joints of the robot arm, with S1 being the base joint and S5 being the end effector joint. The lengths of the links between these joints are as follows:
- L1 (between S1 and S2): 6.335 inches. Note that S2 will be at (0, 0, 6.335) always, since it is directly above S1, which rotates about the z-axis.
- L2 (between S2 and S3): 10.0 inches
- L3 (between S3 and S4): 8.0 inches
- L4 (between S4 and S5): 3.209 inches
- L5 (between S5 and the connector ending): 1.143 inch (the length to the connector - note that this distance is an extension of the L4 distance, and the significance is that the 'twist' along the L4/L5 link if at this point)
- L6 - this is essentially the link from the end of the connector to the tip of the end effectors. This will vary for each attachment, and will not always be centered on the end of the connector. Let's define a coordinate system for the end of the connector, with the z-axis pointing outwards from the connector, the x-axis pointing to the right of the connector, and the y-axis pointing upwards along the connector. Let the origin be that end of L5. The the L6 coordinates for each attachment are as follows:
   1. Probe: (0.0, 0.0, 5.350)
   2. Bonesaw: (0.0, 4.705, 2.197)
   3. Vaccuum: (0.0, 0.0, 2.635) 

For joint rotational limits (these need to be verified/calibrated, but are ballpark estimates):
- S1: -129 degree to 156 degrees (with 0 degrees being the position where the arm is pointing directly towards the docking station, and positive rotation being counterclockwise when looking down from above). The limit switch will be at the lower limit.
- S2: -94.16 degree to 86 degrees (with 0 degrees being the position where the arm is fully extended vertically upwards, and positive rotation being counterclockwise. So all stages are at their zero, decreasing S2 will lower the arm towards the +X axis) The limit switch will be at the lower limit.
- S3: -113 degree to 79.6 degrees (with 0 degrees being the position where the arm is straight vertical up when all stages are at their zero, and negative rotation will lower the arm towards the +X axis when all stages are zero). The limit switch will be at the lower limit.
- S4: -83 degree to 79 degrees (with 0 degrees being the position where the arm is straight vertical up when all stages are at their zero, and negative rotation will lower the arm towards the +X axis when all stages are zero). The limit switch will be at the lower limit.
- S5: -180 degrees to 180 degrees (with 0 degrees being the position where the end effector is in its default orientation, and positive rotation being counterclockwise when looking along the L4/L5 link from S4 towards S5). The limit is a hall effect at -180 degrees.

Stage steps pre revolution (with 16x microstepping):
- S1: 16640
- S2: 57600
- S3: 38400
- S4: 33600
- S5: 3200

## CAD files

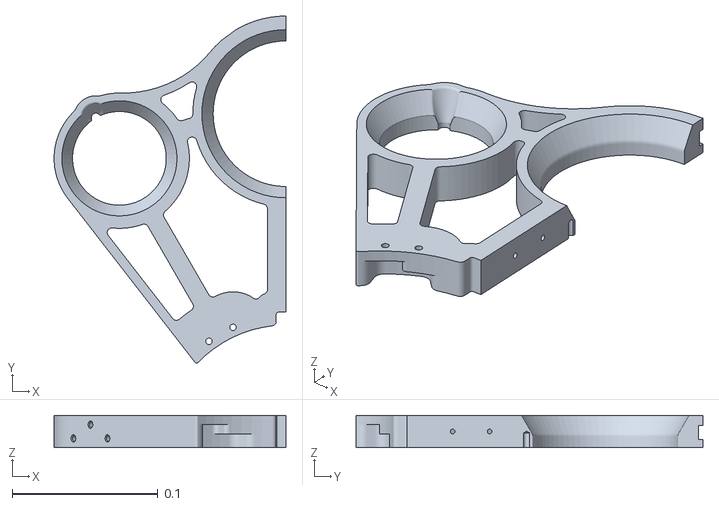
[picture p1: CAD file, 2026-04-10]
ros-py/ros_def/ramses_robot_description/meshes/ds_leftframe_002.stl
0.159 x 0.238 x 0.0222

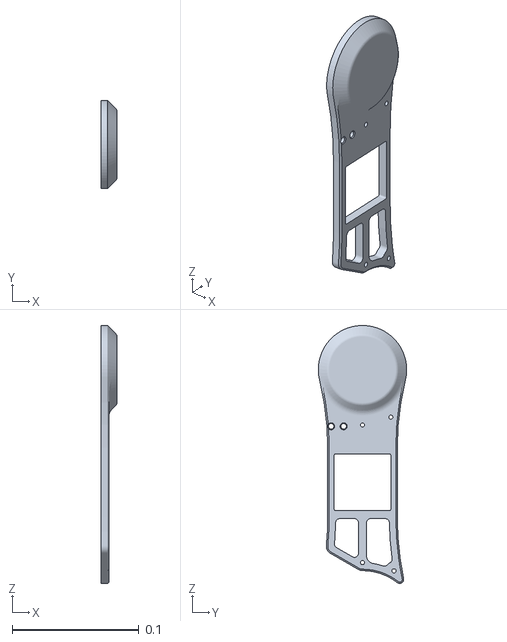
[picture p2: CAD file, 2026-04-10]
ros-py/ros_def/ramses_robot_description/meshes/s3_cover1_021.stl
0.0127 x 0.0698 x 0.204

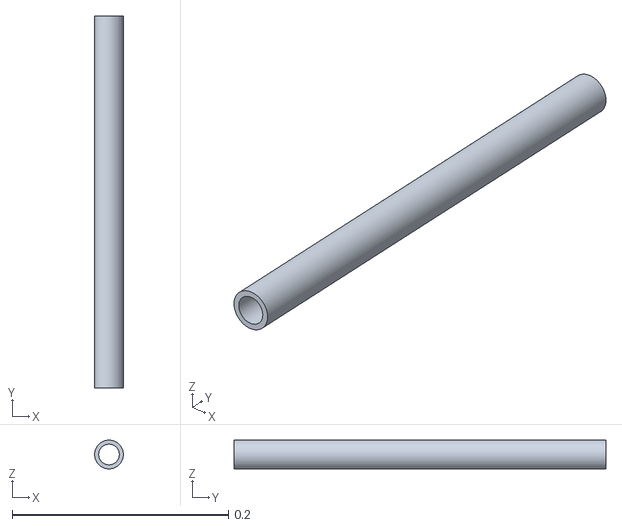
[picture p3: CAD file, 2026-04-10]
ros-py/ros_def/ramses_robot_description/meshes/tc_pvc_13_546.stl
0.0267 x 0.344 x 0.0267

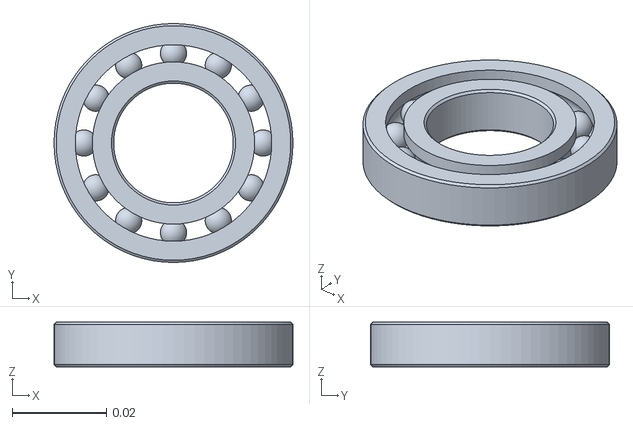
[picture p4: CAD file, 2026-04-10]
ros-py/ros_def/ramses_robot_description/meshes/composite_part_1__2.stl
0.0508 x 0.0508 x 0.00953

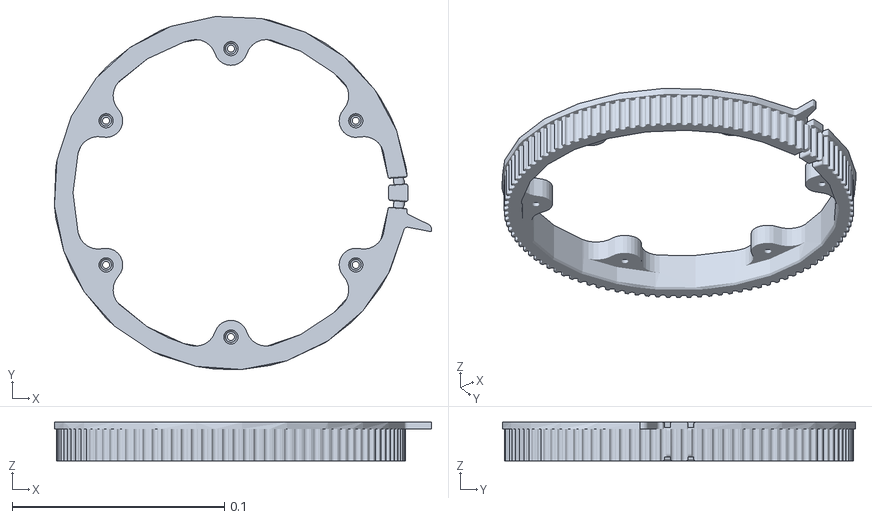
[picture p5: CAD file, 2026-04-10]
ros-py/ros_def/ramses_robot_description/meshes/104t_ringpulley.stl
0.178 x 0.166 x 0.0182

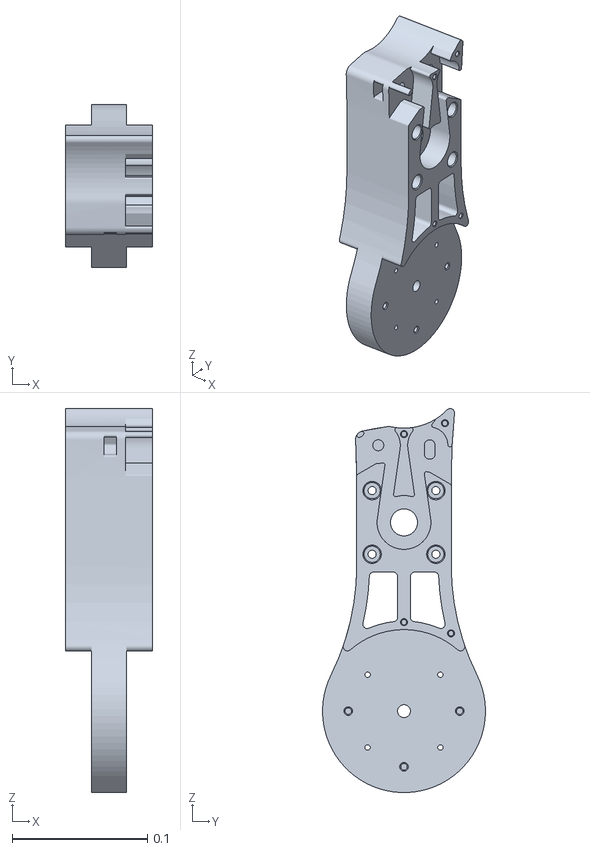
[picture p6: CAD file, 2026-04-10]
ros-py/ros_def/ramses_robot_description/meshes/part_7__2.stl
0.0643 x 0.121 x 0.284

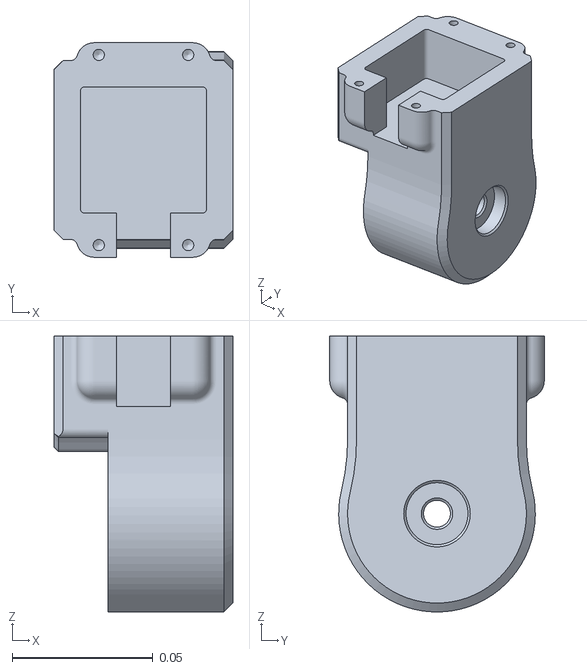
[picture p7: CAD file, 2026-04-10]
ros-py/ros_def/ramses_robot_description/meshes/s4_core_020.stl
0.0635 x 0.0762 x 0.098

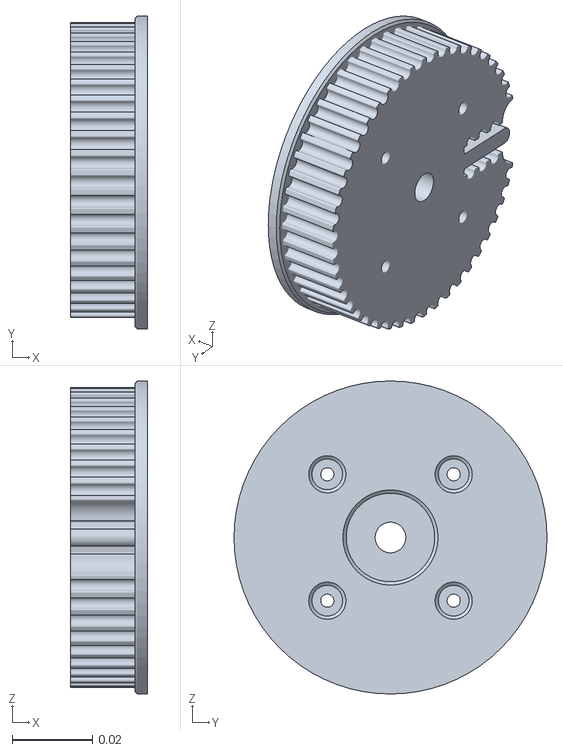
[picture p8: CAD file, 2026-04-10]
ros-py/ros_def/ramses_robot_description/meshes/48t_pulley.stl
0.0192 x 0.0779 x 0.0779

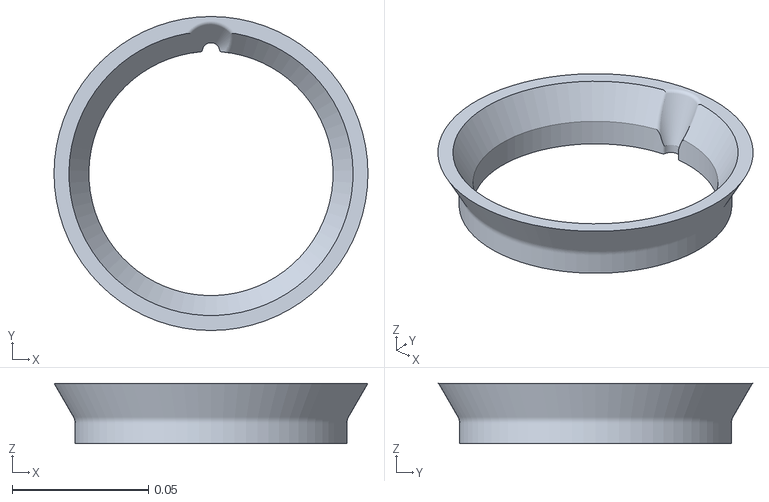
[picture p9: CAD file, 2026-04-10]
ros-py/ros_def/ramses_robot_description/meshes/ds_centraldockadapter_001.stl
0.115 x 0.115 x 0.0222

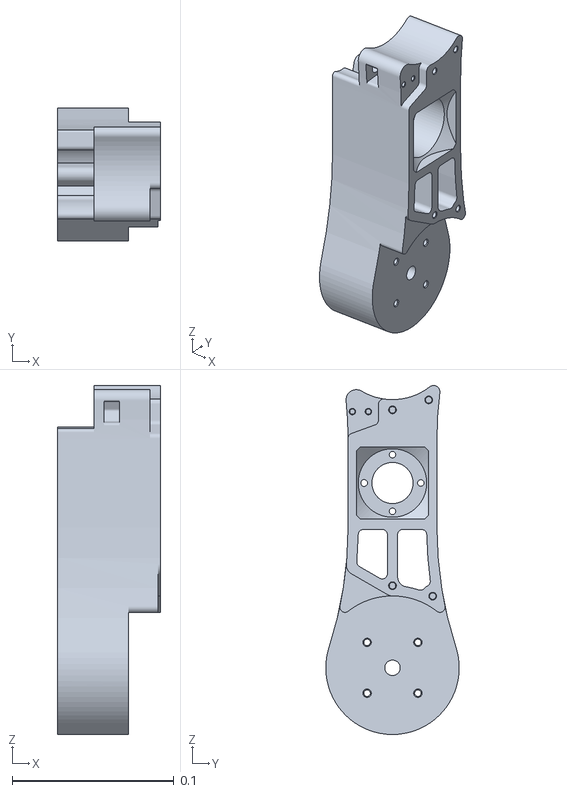
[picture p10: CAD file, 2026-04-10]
ros-py/ros_def/ramses_robot_description/meshes/s3_core_024.stl
0.0635 x 0.0825 x 0.216

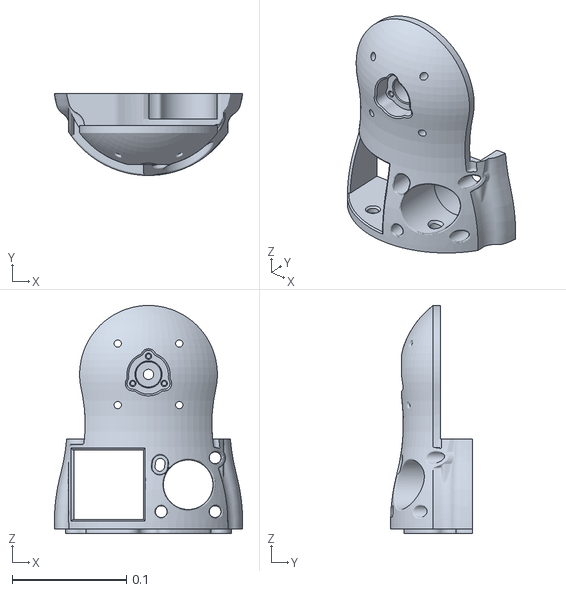
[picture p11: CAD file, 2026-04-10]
ros-py/ros_def/ramses_robot_description/meshes/s1_pile2_007.stl
0.165 x 0.0717 x 0.2

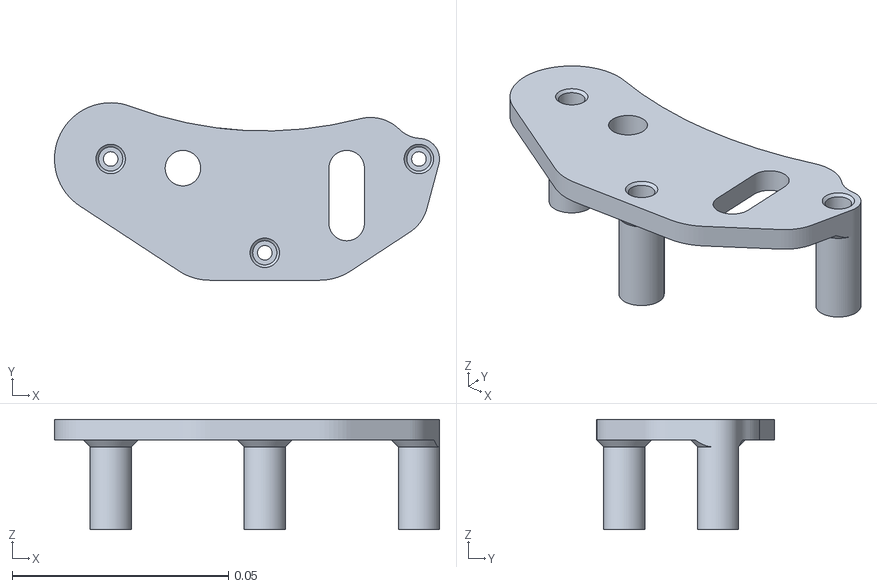
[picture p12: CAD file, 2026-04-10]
ros-py/ros_def/ramses_robot_description/meshes/b_tensionstandoff_011.stl
0.089 x 0.0411 x 0.0255

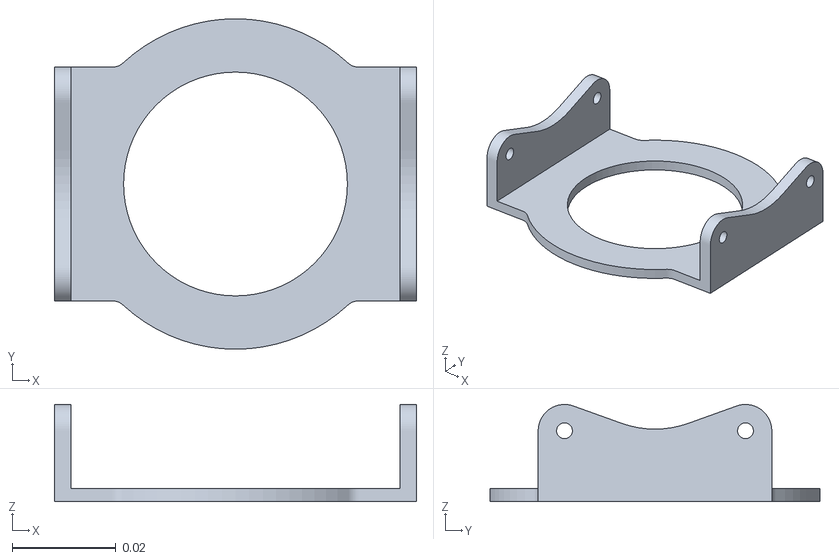
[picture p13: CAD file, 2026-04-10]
ros-py/ros_def/ramses_robot_description/meshes/part_2__2.stl
0.0698 x 0.0638 x 0.0187

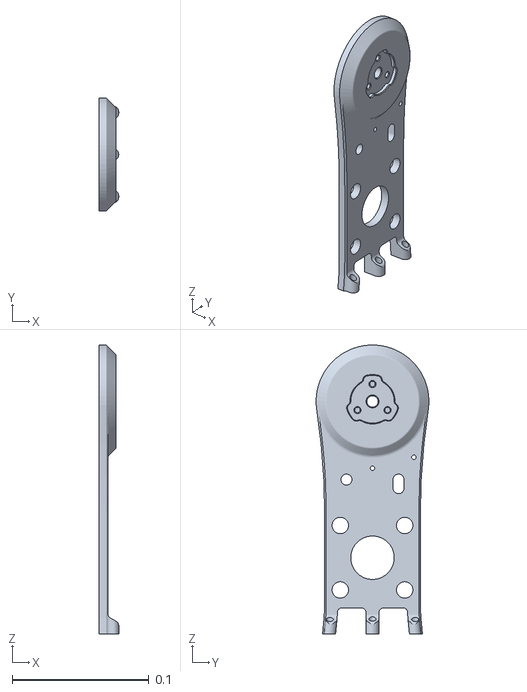
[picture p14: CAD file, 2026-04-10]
ros-py/ros_def/ramses_robot_description/meshes/part_11__2.stl
0.0143 x 0.0825 x 0.211

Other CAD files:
ros-py/ros_def/ramses_robot_description/meshes/ds_rightframe_003.stl
ros-py/ros_def/ramses_robot_description/meshes/nema17_5_1_gearbox.stl
ros-py/ros_def/ramses_robot_description/meshes/42t_pulley.stl
ros-py/ros_def/ramses_robot_description/meshes/90_fitting.stl
ros-py/ros_def/ramses_robot_description/meshes/b_limitmount_017.stl
ros-py/ros_def/ramses_robot_description/meshes/b_motorplate_010.stl
ros-py/ros_def/ramses_robot_description/meshes/b_pvcmount_012.stl
ros-py/ros_def/ramses_robot_description/meshes/b_turntablebase_001.stl
ros-py/ros_def/ramses_robot_description/meshes/hex_nut_grade_a___b_m8x1_25__3430b5bbd516b81b52e50f5ca3422a70.stl
ros-py/ros_def/ramses_robot_description/meshes/hex_socket_head_cap_screw_m8x1_25_x_25__a9f2d9bcc6cdc071be143b59fb9dc981.stl
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

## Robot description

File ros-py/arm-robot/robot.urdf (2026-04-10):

<?xml version="1.0" ?>
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
<robot name="C:\Users\conno\Documents\me424-robot\ros-py\arm-robot">

  <link name="world"/>

  <joint name="world_to_base" type="fixed">
    <parent link="world"/>
    <child link="b_turntablebase_001"/>
    <origin xyz="0 0 0" rpy="0 0 0"/>
  </joint>

  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
  <link name="b_turntablebase_001">
    <inertial>
      <origin xyz="8.72341e-05 0.0429888 0.00589545" rpy="0 0 0"/>
      <mass value="7.61097"/>
      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
    </inertial>
    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
  </link>
  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
  <link name="s1_bearingplug_003">
    <inertial>
      <origin xyz="-0.000130278 1.2507e-05 0.0992505" rpy="0 0 0"/>
      <mass value="1.95427"/>
      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
    </inertial>
    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
  </link>
  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
  <link name="nema23_2_0nm">
    <inertial>
      <origin xyz="0.000285325 -0.0920124 -0.0388436" rpy="0 0 0"/>
      <mass value="1.29278"/>
      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
    </inertial>
    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
  </link>
  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
  <link name="nema17_5_1_gearbox">
    <inertial>
      <origin xyz="-0.000154674 -0.0786034 -0.0285654" rpy="0 0 0"/>
      <mass value="0.798546"/>
      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
    </inertial>
    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
  </link>
  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
  <link name="s4_core_020">
    <inertial>
      <origin xyz="0.000773028 0.0242398 -0.0265345" rpy="0 0 0"/>
      <mass value="0.374744"/>
      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
    </inertial>
    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
  </link>
  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
  <link name="s5_armconnector_036">
    <inertial>
      <origin xyz="0.000375764 -5.61588e-07 -0.0133012" rpy="0 0 0"/>
      <mass value="0.0706859"/>
      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
    </inertial>
    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
  </link>
  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
  <joint name="s5_wrist_twist" type="revolute">
    <origin xyz="-0 0.0789686 -0.03175" rpy="1.5708 -0.536359 -0"/>
    <parent link="s4_core_020"/>
    <child link="s5_armconnector_036"/>
    <axis xyz="0 0 1"/>
    <limit effort="10" velocity="10" lower="-0.536359" upper="5.74683"/>
  </joint>
  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
  <joint name="s4_wrist" type="revolute">
    <origin xyz="-0 -0.2032 -0.0635" rpy="-3.14159 -0 0.687129"/>
    <parent link="nema17_5_1_gearbox"/>
    <child link="s4_core_020"/>
    <axis xyz="0 0 1"/>
    <limit effort="10" velocity="10" lower="-0.709134" upper="2.22302"/>
  </joint>
  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
  <joint name="s3_elbow" type="revolute">
    <origin xyz="0 -0.254 -0.0070104" rpy="-0 0 -1.87906"/>
    <parent link="nema23_2_0nm"/>
    <child link="nema17_5_1_gearbox"/>
    <axis xyz="0 0 1"/>
    <limit effort="10" velocity="10" lower="-0.0757129" upper="3.32768"/>
  </joint>
  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
  <joint name="s2_shoulder" type="revolute">
    <origin xyz="-0 -0.0385064 0.179503" rpy="-1.5708 -0.698555 -3.14159"/>
    <parent link="s1_bearingplug_003"/>
    <child link="nema23_2_0nm"/>
    <axis xyz="0 0 1"/>
    <limit effort="10" velocity="10" lower="-1.13404" upper="2.26935"/>
  </joint>
  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
  <joint name="s1_turntable" type="revolute">
    <origin xyz="-0 0 0.0036195" rpy="0 0 1.61412"/>
    <parent link="b_turntablebase_001"/>
    <child link="s1_bearingplug_003"/>
    <axis xyz="0 0 1"/>
    <limit effort="10" velocity="10" lower="-2.27734" upper="2.57467"/>
  </joint>
</robot>

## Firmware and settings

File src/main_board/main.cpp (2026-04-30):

#include <Arduino.h>
#include <cstring>
#include <WiFi.h>
#include <ArduinoOTA.h>
#include <FS.h>
#include <LittleFS.h>
#include <WebServer.h>
#include <WebSocketsServer.h>
#include <Preferences.h>

// Version 12.7

#ifndef WIFI_SSID
#define WIFI_SSID "surgical_clanker2.4"
#endif
#ifndef WIFI_PASSWORD
#define WIFI_PASSWORD "bone_saw"
#endif
#ifndef WIFI_HOSTNAME
#define WIFI_HOSTNAME "me424-main"
#endif

WiFiServer CommandServer(3333);
WiFiClient commandClient;

WebServer httpServer(80);
WebSocketsServer webSocket(81);
bool webSocketLive = false;

// Never call broadcastTXT from inside webSocketEvent (e.g. during handleCommand) — it drops clients.
// Queue lines here; wsTxFlush() runs after webSocket.loop().
// printHelp() alone is ~70 lines; keep headroom so WebSocket clients see the full list (e.g. "ip" under Other:).
#define WS_TX_QUEUE_DEPTH 160
static String wsTxQueue[WS_TX_QUEUE_DEPTH];
static uint8_t wsTxQueueLen = 0;

static void wsTxEnqueue(const String &line) {
  if (wsTxQueueLen >= WS_TX_QUEUE_DEPTH) {
    Serial.println(F("WS TX queue overflow (line dropped)"));
    return;
  }
  wsTxQueue[wsTxQueueLen++] = line;
}

static void wsTxFlush() {
  if (!webSocketLive || wsTxQueueLen == 0) return;
  for (uint8_t i = 0; i < wsTxQueueLen; i++) {
    webSocket.broadcastTXT(wsTxQueue[i]);
  }
  wsTxQueueLen = 0;
}
bool httpServerLive = false;

bool DEBUG = false;

// =========================
// Stepper config
// =========================
const int NUM_DRIVERS = 6;

const int STEP_PINS[NUM_DRIVERS] = {25, 33, 32, 27, 26, 4};
const int DIR_PINS[NUM_DRIVERS]  = {13, 14, 22, 21, 23, 15};

int pulseDelayUs = 1000;
long currentPos[NUM_DRIVERS] = {0, 0, 0, 0, 0, 0};
volatile bool estopLatched = false;
String estopSerialBuffer = "";
String estopWifiBuffer = "";

enum QueueItemType {
  Q_POSE = 0,
  Q_DELAY = 1,
  Q_CMD = 2
};

struct QueueItem {
  QueueItemType type;
  long targets[NUM_DRIVERS];
  long maxSps;
  int rampSteps;
  unsigned long delayMs;
  String cmd;
};

const int MAX_QUEUE_ITEMS = 64;
QueueItem runQueueItems[MAX_QUEUE_ITEMS];
int runQueueCount = 0;
bool queueStopRequested = false;

// Stage-to-controller mapping:
// Stage 1 = turntable          -> controller 6 (index 5)
// Stage 2 = base lift pair     -> controllers 1+4 (index 0+3)
// Stage 3 = arm segment        -> controller 2 (index 1)
// Stage 4 = arm segment        -> controller 3 (index 2)
// Stage 5 = wrist              -> controller 5 (index 4)

const int STAGE1       = 5;   // controller 6
const int STAGE2_RIGHT = 0;   // controller 1
const int STAGE3       = 1;   // controller 2
const int STAGE4       = 2;   // controller 3
const int STAGE2_LEFT  = 3;   // controller 4
const int STAGE5       = 4;   // controller 5

const int NUM_STAGES = 5;
/** Per-stage zero step offset: logical = raw + offset(stage). S2 applies to both lift motors (C1+C4). Persisted as zs0..zs4. */
long zeroStepOffsetByStage[NUM_STAGES] = {0, 0, 0, 0, 0};

static long zeroOffsetForDriver(int driverIdx) {
  if (driverIdx == STAGE1) return zeroStepOffsetByStage[0];
  if (driverIdx == STAGE2_RIGHT || driverIdx == STAGE2_LEFT) return zeroStepOffsetByStage[1];
  if (driverIdx == STAGE3) return zeroStepOffsetByStage[2];
  if (driverIdx == STAGE4) return zeroStepOffsetByStage[3];
  if (driverIdx == STAGE5) return zeroStepOffsetByStage[4];
  return 0;
}

void enforceStage2PairTarget(long targets[NUM_DRIVERS]) {
  // Stage 2 must always remain paired (controllers 1 and 4).
  // Use C1 as the authoritative value when both are provided.
  targets[STAGE2_LEFT] = targets[STAGE2_RIGHT];
}

static void loadZeroStepOffsets() {
  Preferences prefs;
  if (!prefs.begin("me424", true)) return;
  for (int s = 0; s < NUM_STAGES; s++) {
    String k = "zs" + String(s);
    if (prefs.isKey(k.c_str())) zeroStepOffsetByStage[s] = prefs.getLong(k.c_str(), 0);
  }
  prefs.end();
}

static void saveZeroStepOffsets() {
  Preferences prefs;
  if (!prefs.begin("me424", false)) return;
  for (int s = 0; s < NUM_STAGES; s++) {
    String k = "zs" + String(s);
    prefs.putLong(k.c_str(), zeroStepOffsetByStage[s]);
  }
  prefs.end();
}

/** User/logical coordinates = raw motor counts + per-stage offset (S2 → C1+C4). */
static void logicalPosFromRaw(long logicalOut[NUM_DRIVERS]) {
  currentPos[STAGE2_LEFT] = currentPos[STAGE2_RIGHT];
  for (int i = 0; i < NUM_DRIVERS; i++) {
    logicalOut[i] = currentPos[i] + zeroOffsetForDriver(i);
  }
  logicalOut[STAGE2_LEFT] = logicalOut[STAGE2_RIGHT];
}

static void rawTargetsFromLogical(const long logical[NUM_DRIVERS], long rawOut[NUM_DRIVERS]) {
  long paired[NUM_DRIVERS];
  for (int i = 0; i < NUM_DRIVERS; i++) paired[i] = logical[i];
  enforceStage2PairTarget(paired);
  for (int i = 0; i < NUM_DRIVERS; i++) {
    rawOut[i] = paired[i] - zeroOffsetForDriver(i);
  }
  rawOut[STAGE2_LEFT] = rawOut[STAGE2_RIGHT];
}

bool invertMotor[NUM_DRIVERS] = {
  false, // controller 1 / stage 2 right
  false, // controller 2 / stage 3
  true,  // controller 3 / stage 4 (reversed)
  true,  // controller 4 / stage 2 left
  false, // controller 5 / stage 5
  false  // controller 6 / stage 1 (turntable)
};

// =========================
// UART to MOSFET slave (or merge tool UART onto sensor link — see MOSFET_OVER_SENSOR_UART)
// Assumes RX2/TX2 map to GPIO16/GPIO17 on your board.
// If not, change these.
// =========================
HardwareSerial SlaveSerial(2);
const int SLAVE_RX_PIN = 16;   // main RX2
const int SLAVE_TX_PIN = 17;   // main TX2
const long SLAVE_BAUD = 115200;

// =========================
// UART to sensor board
// Sensor TX(27) -> Main RX(18)
// Sensor RX(26) <- Main TX(19)
// =========================
HardwareSerial SensorSerial(1);
const int SENSOR_RX_PIN = 18;   // main RX from sensor TX
const int SENSOR_TX_PIN = 19;   // main TX to sensor RX
const long SENSOR_BAUD = 115200;

// =========================
// Limit states from sensor board
// true = switch hit
// =========================
volatile bool stage1CWLimitHit = false;
volatile bool stage2LimitHit = false;
volatile bool stage3LimitHit = false;
volatile bool stage4LimitHit = false;
// Stage 5: Hall + HW-477 on sensor board GPIO14 — homing/zero only, not a motion limit
volatile bool stage5HallAtZero = false;
String lastSensorLimMsg = "";

// =========================
// Buffers
// =========================
String serialBuffer = "";
String wifiBuffer = "";
String slaveBuffer = "";
String sensorBuffer = "";

// Forward declarations used by queue/emergency helpers
void handleCommand(String cmd);
void readFromSlave();

void webSocketEvent(uint8_t num, WStype_t type, uint8_t *payload, size_t length) {
  if (type == WStype_TEXT) {
    String s;
    s.reserve(length);
    for (size_t i = 0; i < length; i++) s += (char)payload[i];
    s.trim();
    if (s.length()) handleCommand(s);
  } else if (type == WStype_CONNECTED) {
    webSocket.sendTXT(num, "WS: connected to ME424 main");
  }
}

static void httpSendLittleFSFile(const char *path, const char *mime) {
  if (!LittleFS.exists(path)) {
    httpServer.send(404, "text/plain",
                    String("LittleFS missing: ") + path +
                        " — put index.html, app.js, styles.css in data/ then: pio run -e main_board -t uploadfs");
    return;
  }
  File f = LittleFS.open(path, "r");
  if (!f) {
    httpServer.send(500, "text/plain", "LittleFS open failed");
    return;
  }
  httpServer.streamFile(f, mime);
  f.close();
}

// =========================
// Output helpers
//
// printlnControl() — machine-readable protocol lines (always emitted on Serial).
//   Used for ACK / DONE / ERR / state-report lines that the ROS bridge parses.
//
// printlnDebug() — verbose human-readable noise, gated by the DEBUG flag.
//   Send  "debug on"  /  "debug off"  at runtime to toggle without reflashing.
//
// printlnBoth() — legacy broadcast to Serial + WiFi TCP + WebSocket.
//   Kept for WiFi-facing status messages (WebSocket UI, TCP client).
//   In serial-only mode it behaves identically to printlnControl().
// =========================

void printlnControl(const String &msg) {
  Serial.println(msg);
  // Also mirror to WiFi clients so the web UI stays in sync when WiFi is active.
  if (commandClient && commandClient.connected()) commandClient.println(msg);
  if (webSocketLive) {
    String wscopy = msg;
    webSocket.broadcastTXT(wscopy);
  }
}

void printlnDebug(const String &msg) {
  if (DEBUG) Serial.println("[DBG] " + msg);
}

// printlnBoth is retained for call-sites that genuinely want WiFi broadcast
// (sensor events, slave relay lines, startup banners).  It does NOT go through
// printlnControl so debug noise never leaks into the control stream.
void printBoth(const String &msg) {
  if (DEBUG) Serial.print(msg);
  if (commandClient && commandClient.connected()) commandClient.print(msg);
  if (webSocketLive) {
    wsTxEnqueue(msg);
  }
}

void printlnBoth(const String &msg) {
  if (DEBUG) Serial.println(msg);
  if (commandClient && commandClient.connected()) commandClient.println(msg);
  if (webSocketLive) {
    wsTxEnqueue(msg);
  }
}

// --- Protocol helpers ---
// Always call these (not printlnBoth) for ROS-parseable responses.

void sendACK(const String &tag) {
  printlnControl("ACK " + tag);
}

void sendDONE(const String &tag) {
  printlnControl("DONE " + tag);
}

void sendERR(const String &tag, const String &reason) {
  printlnControl("ERR " + tag + " " + reason);
}

void sendToSlave(const String &msg) {
#if defined(MOSFET_OVER_SENSOR_UART)
  // Sensor ESP32 handles limits + tool on one UART. "STATUS" here means MOSFET-style tool status
  // (main "limits" command sends STATUS directly on SensorSerial, not via sendToSlave).
  String out = msg;
  if (out == "STATUS") {
    out = "MSTATUS";
  }
  SensorSerial.println(out);
  printlnBoth("[TO SENSOR/MOS] " + out);
#else
  SlaveSerial.println(msg);
  printlnBoth("[TO SLAVE] " + msg);
#endif
}

void parseEStopLine(String line) {
  line.trim();
  line.toLowerCase();
  if (line == "estop") {
    estopLatched = true;
    sendToSlave("ALL OFF");
    printlnControl("ESTOP LATCHED");
  } else if (line == "estop clear") {
    estopLatched = false;
    printlnControl("ESTOP CLEARED");
  }
}

void pollEmergencyInputs() {
  while (Serial.available()) {
    char c = (char)Serial.read();
    if (c == '\r') continue;
    if (c == '\n') {
      if (estopSerialBuffer.length() > 0) {
        parseEStopLine(estopSerialBuffer);
        estopSerialBuffer = "";
      }
    } else {
      estopSerialBuffer += c;
    }
  }

  if (commandClient && commandClient.connected()) {
    while (commandClient.available()) {
      char c = (char)commandClient.read();
      if (c == '\r') continue;
      if (c == '\n') {
        if (estopWifiBuffer.length() > 0) {
          parseEStopLine(estopWifiBuffer);
          estopWifiBuffer = "";
        }
      } else {
        estopWifiBuffer += c;
      }
    }
  }
}

void printLimitStatus() {
  // S5H: 0 = at Hall zero, 1 = away (unlike S2–S4 where 1 = limit hit).
  printlnControl("LIMITS S1=" + String(stage1CWLimitHit ? "1" : "0") +
              " S2=" + String(stage2LimitHit ? "1" : "0") +
              " S3=" + String(stage3LimitHit ? "1" : "0") +
              " S4=" + String(stage4LimitHit ? "1" : "0") +
              " S5H=" + String(stage5HallAtZero ? "0" : "1"));
}

void parseSensorMessage(String msg) {
  msg.trim();
  msg.toUpperCase();

  if (!msg.startsWith("LIM ")) {
#if defined(MOSFET_OVER_SENSOR_UART)
    if (msg.startsWith("STATUS MAG=") || msg.startsWith("ACK ") || msg.startsWith("ERR ")) {
      printlnBoth("[MOS] " + msg);
    }
#endif
    return;
  }

  const bool prevS1 = stage1CWLimitHit;
  const bool prevS2 = stage2LimitHit;
  const bool prevS3 = stage3LimitHit;
  const bool prevS4 = stage4LimitHit;
  const bool prevS5Hall = stage5HallAtZero;

  // Space-prefixed tokens avoid false matches (e.g. stray "S1=" in other fields).
  // If S1 is missing from the line, clear turntable CW limit (stale S1=1 was blocking s1cw / c6f).
  int s1p = msg.indexOf(" S1=");
  if (s1p >= 0 && s1p + 4 < (int)msg.length()) {
    char c1 = msg.charAt(s1p + 4);
    if (c1 == '1') stage1CWLimitHit = true;
    else if (c1 == '0') stage1CWLimitHit = false;
  } else {
    stage1CWLimitHit = false;
  }

  int s2pos = msg.indexOf(" S2=");
  int s3pos = msg.indexOf(" S3=");
  int s4pos = msg.indexOf(" S4=");
  int s5hpos = msg.indexOf(" S5H=");

  if (s2pos >= 0 && s2pos + 4 < (int)msg.length()) {
    char c2 = msg.charAt(s2pos + 4);
    if (c2 == '1') stage2LimitHit = true;
    else if (c2 == '0') stage2LimitHit = false;
  }
  if (s3pos >= 0 && s3pos + 4 < (int)msg.length()) {
    char c3 = msg.charAt(s3pos + 4);
    if (c3 == '1') stage3LimitHit = true;
    else if (c3 == '0') stage3LimitHit = false;
  }
  if (s4pos >= 0 && s4pos + 4 < (int)msg.length()) {
    char c4 = msg.charAt(s4pos + 4);
    if (c4 == '1') stage4LimitHit = true;
    else if (c4 == '0') stage4LimitHit = false;
  }
  if (s5hpos >= 0 && s5hpos + 5 < (int)msg.length()) {
    bool s5 = (msg.charAt(s5hpos + 5) == '0');
    stage5HallAtZero = s5;
    if (s5 && !prevS5Hall) {
      printlnDebug("S5 HALL: at zero (sensor)");
    } else if (!s5 && prevS5Hall) {
      printlnDebug("S5 HALL: left zero zone");
    }
  }

  bool stateChanged = (prevS1 != stage1CWLimitHit) ||
                      (prevS2 != stage2LimitHit) ||
                      (prevS3 != stage3LimitHit) ||
                      (prevS4 != stage4LimitHit) ||
                      (prevS5Hall != stage5HallAtZero);
  if (stateChanged || msg != lastSensorLimMsg) {
    // printlnBoth("[SENSOR] " + msg);
    printlnDebug("[SENSOR] " + msg);
    lastSensorLimMsg = msg;
  }
}

void serviceSensorUART() {
  while (SensorSerial.available()) {
    char c = (char)SensorSerial.read();

    if (c == '\r') continue;
    if (c == '\n') {
      if (sensorBuffer.length() > 0) {
        parseSensorMessage(sensorBuffer);
        sensorBuffer = "";
      }
    } else {
      sensorBuffer += c;
    }
  }
}

// =========================
// Direction-aware limit logic
//
// Stage 2:  s2down -> forward=false (blocked by limit)
// Stage 3:  s3down -> forward=true  (blocked by limit)
// Stage 4:  s4down -> forward=true  (blocked by limit)
// Stage 1: turntable CW limit on sensor D13 — blocks s1cw only (CCW still allowed).
// Stage 5: no limit switch blocking (Hall S5H is for homing only, not hard stop)
// =========================
bool shouldStopMotor(int motorIndex, bool forward) {
  if (motorIndex == STAGE1) {
    bool movingCW = forward;
    return stage1CWLimitHit && movingCW;
  }

  if (motorIndex == STAGE2_RIGHT || motorIndex == STAGE2_LEFT) {
    bool movingDown = !forward;
    return stage2LimitHit && movingDown;
  }

  if (motorIndex == STAGE3) {
    bool movingDown = forward;
    return stage3LimitHit && movingDown;
  }

  if (motorIndex == STAGE4) {
    bool movingDown = forward;
    return stage4LimitHit && movingDown;
  }

  return false;
}

void setDirectionRaw(int motorIndex, bool forward) {
  digitalWrite(DIR_PINS[motorIndex], forward ? HIGH : LOW);
}

void setDirection(int motorIndex, bool forward) {
  bool actualForward = invertMotor[motorIndex] ? !forward : forward;
  setDirectionRaw(motorIndex, actualForward);
  delayMicroseconds(50);
}

// =========================
// Motion functions
// =========================
bool stepMotor(int motorIndex, bool forward, int steps) {
  if (estopLatched) {
    printlnDebug("ESTOP: motion blocked");
    return false;
  }
  serviceSensorUART();
  int movedSteps = 0;

  if (shouldStopMotor(motorIndex, forward)) {
    printlnDebug("ABORT: limit active for controller " + String(motorIndex + 1) +
                " in requested direction");
    return false;
  }

  setDirection(motorIndex, forward);

  for (int i = 0; i < steps; i++) {
    pollEmergencyInputs();
    if (estopLatched) {
      printlnDebug("ESTOP: controller " + String(motorIndex + 1) + " stopped");
      currentPos[motorIndex] += forward ? movedSteps : -movedSteps;
      return false;
    }
    serviceSensorUART();

    if (shouldStopMotor(motorIndex, forward)) {
      printlnDebug("STOP: limit hit on controller " + String(motorIndex + 1));
      currentPos[motorIndex] += forward ? movedSteps : -movedSteps;
      return false;
    }

    digitalWrite(STEP_PINS[motorIndex], HIGH);
    delayMicroseconds(pulseDelayUs);
    digitalWrite(STEP_PINS[motorIndex], LOW);
    delayMicroseconds(pulseDelayUs);
    movedSteps++;
  }

  currentPos[motorIndex] += forward ? movedSteps : -movedSteps;
  return true;
}

/** Match syncabs timing: half-period delay so average rate ~= sps steps/s. */
static bool stepMotorAtSps(int motorIndex, bool forward, int steps, int sps) {
  int saved = pulseDelayUs;
  int spsClamped = max(1, sps);
  pulseDelayUs = max(100, (int)(500000L / (long)spsClamped));
  bool ok = stepMotor(motorIndex, forward, steps);
  pulseDelayUs = saved;
  return ok;
}

bool stepStage2(bool forward, int steps) {
  if (estopLatched) {
    printlnDebug("ESTOP: motion blocked");
    return false;
  }
  serviceSensorUART();
  int movedSteps = 0;

  bool movingDown = !forward;
  if (stage2LimitHit && movingDown) {
    printlnDebug("ABORT: Stage 2 limit already active for downward motion");
    return false;
  }

  setDirection(STAGE2_RIGHT, forward);
  setDirection(STAGE2_LEFT, forward);

  for (int i = 0; i < steps; i++) {
    pollEmergencyInputs();
    if (estopLatched) {
      printlnDebug("ESTOP: Stage 2 stopped");
      long d = forward ? movedSteps : -movedSteps;
      currentPos[STAGE2_RIGHT] += d;
      currentPos[STAGE2_LEFT]  += d;
      return false;
    }
    serviceSensorUART();

    if (stage2LimitHit && movingDown) {
      printlnDebug("STOP: Stage 2 limit hit");
      long delta = forward ? movedSteps : -movedSteps;
      currentPos[STAGE2_RIGHT] += delta;
      currentPos[STAGE2_LEFT]  += delta;
      return false;
    }

    digitalWrite(STEP_PINS[STAGE2_RIGHT], HIGH);
    digitalWrite(STEP_PINS[STAGE2_LEFT], HIGH);
    delayMicroseconds(pulseDelayUs);

    digitalWrite(STEP_PINS[STAGE2_RIGHT], LOW);
    digitalWrite(STEP_PINS[STAGE2_LEFT], LOW);
    delayMicroseconds(pulseDelayUs);
    movedSteps++;
  }

  long delta = forward ? movedSteps : -movedSteps;
  currentPos[STAGE2_RIGHT] += delta;
  currentPos[STAGE2_LEFT]  += delta;
  return true;
}

void runControllerCommand(int controllerNum, bool forward, int steps) {
  int motorIndex = controllerNum - 1;

  if (motorIndex < 0 || motorIndex >= NUM_DRIVERS) {
    sendERR("c" + String(controllerNum), "invalid controller");
    return;
  }

  bool ok = false;
  if (motorIndex == STAGE2_RIGHT || motorIndex == STAGE2_LEFT) {
    ok = stepStage2(forward, steps);
  } else {
    ok = stepMotor(motorIndex, forward, steps);
  }

  printlnDebug("Controller " + String(controllerNum) +
               (forward ? " forward " : " reverse ") + String(steps) + " steps " +
               (ok ? "done" : "aborted"));
  // DONE/ERR is sent by the handleCommand caller after this returns
  // (raw controller path sends them inline in handleCommand)
}

// =========================
// Sequential / parallel execution
//
// MotorMove holds a single motor's move parameters.
// Stage 2 expands to two MotorMove entries (RIGHT + LEFT).
// =========================
struct MotorMove {
  int  motorIndex;
  bool forward;
  int  stepsRemaining;
  int  originalSteps;
};

// Translate one stage/controller command string into MotorMove entries.
// Returns number of entries written (0 = unrecognised or bad step count).
int resolveToMoves(String cmd, MotorMove *moves, int maxMoves) {
  cmd.trim();
  cmd.toLowerCase();

  int steps = 0;
  int spPos = cmd.lastIndexOf(' ');
  if (spPos > 0) steps = cmd.substring(spPos + 1).toInt();
  if (steps <= 0) return 0;

  // Stage 1 — turntable
  if (cmd.startsWith("s1cw "))  { moves[0] = {STAGE1, true,  steps, steps}; return 1; }
  if (cmd.startsWith("s1ccw ")) { moves[0] = {STAGE1, false, steps, steps}; return 1; }

  // Stage 2 — paired motors
  if (cmd.startsWith("s2up ")) {
    if (maxMoves < 2) return 0;
    moves[0] = {STAGE2_RIGHT, true, steps, steps};
    moves[1] = {STAGE2_LEFT,  true, steps, steps};
    return 2;
  }
  if (cmd.startsWith("s2down ")) {
    if (maxMoves < 2) return 0;
    moves[0] = {STAGE2_RIGHT, false, steps, steps};
    moves[1] = {STAGE2_LEFT,  false, steps, steps};
    return 2;
  }

  // Stage 3
  if (cmd.startsWith("s3up "))   { moves[0] = {STAGE3, false, steps, steps}; return 1; }
  if (cmd.startsWith("s3down ")) { moves[0] = {STAGE3, true,  steps, steps}; return 1; }

  // Stage 4
  if (cmd.startsWith("s4up "))   { moves[0] = {STAGE4, false, steps, steps}; return 1; }
  if (cmd.startsWith("s4down ")) { moves[0] = {STAGE4, true,  steps, steps}; return 1; }

  // Stage 5
  if (cmd.startsWith("s5cw "))   { moves[0] = {STAGE5, false, steps, steps}; return 1; }
  if (cmd.startsWith("s5ccw "))  { moves[0] = {STAGE5, true,  steps, steps}; return 1; }

  // Raw controller: cXf / cXr
  if (cmd.length() >= 5 && cmd.charAt(0) == 'c') {
    int num     = cmd.charAt(1) - '0';
    char dirCh  = cmd.charAt(2);
    if (num >= 1 && num <= 6 && (dirCh == 'f' || dirCh == 'r')) {
      if (num == 1 || num == 4) {
        if (maxMoves < 2) return 0;
        bool fwd = (dirCh == 'f');
        moves[0] = {STAGE2_RIGHT, fwd, steps, steps};
        moves[1] = {STAGE2_LEFT,  fwd, steps, steps};
        return 2;
      }
      moves[0] = {num - 1, dirCh == 'f', steps, steps};
      return 1;
    }
  }

  return 0;
}
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
// void loop() {
//   readFromSerial();
//   readFromWiFi();
//   readFromSlave();
//   serviceSensorUART();
//   if (httpServerLive) httpServer.handleClient();
//   if (webSocketLive) webSocket.loop();
//   if (WiFi.status() == WL_CONNECTED) ArduinoOTA.handle();
// }

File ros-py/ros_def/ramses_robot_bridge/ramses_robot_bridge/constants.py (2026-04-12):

"""
constants.py
============
Arm geometry and conversion factors for the ME424 5-DOF robotic arm.

Tune these values to match your actual hardware:
  - STEPS_PER_REV  : full steps per motor revolution (usually 200)
  - MICROSTEPS     : microstepping divisor set on your driver (1, 2, 4, 8, 16 ...)
  - GEAR_RATIO     : output turns per motor turn (1.0 if direct drive)

steps_per_output_rev = STEPS_PER_REV * MICROSTEPS * GEAR_RATIO
radians_per_step     = 2π / steps_per_output_rev

Joint names must exactly match those in your URDF / RViz2 robot model.
"""

import math

# ------------------------------------------------------------------
# Per-stage drive configuration
# ------------------------------------------------------------------
#
# microsteps_per_rev = full_steps_per_rev × microstep_divisor
# All stages run at 16x microstepping.
#
# Stage | Full steps/rev | ×16  | microsteps/rev
# ------+----------------+------+---------------
# S1    |   1040         | ×16  |  16640   (turntable,  C6)
# S2    |   3600         | ×16  |  57600   (base lift,  C1+C4)
# S3    |   2400         | ×16  |  38400   (arm seg 1,  C2)
# S4    |   2100         | ×16  |  33600   (arm seg 2,  C3)
# S5    |    200         | ×16  |   3200   (wrist,      C5)
#
# Index matches controller numbering (0-based):
#   0 = C1 / STAGE2_RIGHT (base lift)
#   1 = C2 / STAGE3       (arm segment 1)
#   2 = C3 / STAGE4       (arm segment 2)
#   3 = C4 / STAGE2_LEFT  (base lift, mirrored — same joint as C1)
#   4 = C5 / STAGE5       (wrist)
#   5 = C6 / STAGE1       (turntable)

# Stored as microsteps per full output revolution (already includes gear ratio).
_MICROSTEPS_PER_REV = [
    28800,   # C1 / S2 right  (base lift)
    19200,   # C2 / S3        (arm segment 1)
    16800,   # C3 / S4        (arm segment 2)
    28800,   # C4 / S2 left   (base lift, mirrors C1)
     1600,   # C5 / S5        (wrist)
    8320,   # C6 / S1        (turntable)
]

def _rad_per_step(idx: int) -> float:
    return (2.0 * math.pi) / _MICROSTEPS_PER_REV[idx]


# Pre-computed radians-per-step for each controller index
RAD_PER_STEP = [_rad_per_step(i) for i in range(6)]

# ------------------------------------------------------------------
# Joint names — must match the URDF exactly
# ------------------------------------------------------------------
# Order matches the controller-to-joint mapping used in
# _publish_joint_states (controller_for_joint list).
# JOINT_NAMES = [
#     's1_turntable',   # C6 / S1  — turntable
#     's2_shoulder',    # C1 / S2  — base lift (paired C1+C4, use C1)
#     's3_elbow',       # C2 / S3  — arm segment 1
#     's4_wrist',       # C3 / S4  — arm segment 2
#     's5_wrist_twist', # C5 / S5  — wrist twist
# ]
JOINT_NAMES = [
    's5_wrist_twist',
    's4_wrist',
    's3_elbow',
    's2_shoulder',
    's1_turntable',
]

# ------------------------------------------------------------------
# Serial port defaults (can be overridden by ROS2 parameters)
# ------------------------------------------------------------------
DEFAULT_PORT     = '/dev/ttyUSB0'
DEFAULT_BAUDRATE = 115200

# ------------------------------------------------------------------
# Timeouts
# ------------------------------------------------------------------
# How long to wait for ACK after sending a command (seconds).
ACK_TIMEOUT_S = 2.0

# How long to wait for DONE/ERR after ACK (seconds).
# Set high enough for your longest expected motion.
DONE_TIMEOUT_S = 120.0

# Serial readline timeout (seconds) — keep short so the reader
# thread stays responsive.
SERIAL_READ_TIMEOUT_S = 0.1

# ------------------------------------------------------------------
# Commands treated as fire-and-forget via the /arm/command topic
# (these never wait for DONE — they return immediately after ACK)
# ------------------------------------------------------------------
INSTANT_COMMANDS = {
    'estop', 'estop clear', 'estop status',
    'mag on', 'mag off',
    'vac on', 'vac off',
    'saw on', 'saw off',
    'alloff', 'mstatus',
    'debug on', 'debug off',
    'qclear', 'qstop', 'qstatus', 'qlist',
    'where', 'limits', 'help',
}

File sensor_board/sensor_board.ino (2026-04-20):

#include <Arduino.h>
#include <WiFi.h>
#include <ArduinoOTA.h>
#include <math.h>

#ifndef WIFI_SSID
#define WIFI_SSID ""
#endif
#ifndef WIFI_PASSWORD
#define WIFI_PASSWORD ""
#endif
#ifndef WIFI_HOSTNAME
#define WIFI_HOSTNAME "me424-sensor"
#endif

// UART to main board
// Sensor TX (D27) -> Main RX (D18)
// Sensor RX (D26) <- Main TX (D19)
HardwareSerial MainSerial(1);

const int UART_RX_PIN = 26;
const int UART_TX_PIN = 27;
const long UART_BAUD = 115200;

// --- Tool: MAG/VAC/SAW + tool ID + probe (same protocol as old MOSFET board) ---
// UART to main stays on GPIO26/27 — do not use those for tool.
// MAG=18, VAC=19. SAW: GPIO21 enables saw power MOSFET; GPIO22 is BLDC PWM to driver.
// Tool ID + pot: GPIO34/35 are ADC1 input-only (divider + wiper; never drive them).
const int MAG_PIN = 18;
const int VAC_PIN = 19;
/** Saw load / power-path MOSFET gate (digital). */
const int SAW_MOSFET_PIN = 21;
const int SAW_BLDC_PWM_PIN = 22;
const int SAW_BLDC_PWM_CHANNEL = 0;
const int SAW_BLDC_PWM_FREQ_HZ = 5000;
const int SAW_BLDC_PWM_BITS = 8;

// Tool ID: 3.3V — 10k — node (ADC pin) — tool resistor (2.2k / 5k / 10k) — GND
const int TOOL_ID_ADC_PIN = 34;
const float TOOL_R_SERIES_OHMS = 10000.0f;
const float TOOL_VCC = 3.3f;

// Pot / probe stroke (mm); raw 4095 = free (no compression)
const int POT_ADC_PIN = 35;
const float POT_STROKE_MM = 26.9875f;
const int POT_RAW_FREE = 4095;

static const int TOOL_NOMINAL_OHMS[3] = {2200, 5000, 10000};

/** Magnet auto-off after continuous ON (safety after manual / UI mag on). */
#ifndef MAG_AUTO_OFF_MS
#define MAG_AUTO_OFF_MS 30000UL
#endif

bool magState = false;
/** millis() when MAG last turned on; 0 if MAG off. */
static unsigned long magOnSinceMs = 0;
bool vacState = false;
bool sawState = false;
uint8_t sawSpeedPercent = 0;
bool sawBldcPwmAttached = false;

static void sawBldcPwmInit() {
  ledcSetup(SAW_BLDC_PWM_CHANNEL, SAW_BLDC_PWM_FREQ_HZ, SAW_BLDC_PWM_BITS);
  pinMode(SAW_BLDC_PWM_PIN, OUTPUT);
  digitalWrite(SAW_BLDC_PWM_PIN, LOW);
}

static void sawBldcEnsureAttached() {
  if (sawBldcPwmAttached) return;
  ledcAttachPin(SAW_BLDC_PWM_PIN, SAW_BLDC_PWM_CHANNEL);
  sawBldcPwmAttached = true;
}

static void sawBldcForceLow() {
  if (sawBldcPwmAttached) {
    ledcWrite(SAW_BLDC_PWM_CHANNEL, 0);
    ledcDetachPin(SAW_BLDC_PWM_PIN);
    sawBldcPwmAttached = false;
  }
  pinMode(SAW_BLDC_PWM_PIN, OUTPUT);
  digitalWrite(SAW_BLDC_PWM_PIN, LOW);
}

static void sawBldcApplyDuty(uint32_t duty) {
  sawBldcEnsureAttached();
  ledcWrite(SAW_BLDC_PWM_CHANNEL, duty);
}

static uint32_t sawSpeedDuty() {
  uint32_t duty = (uint32_t)sawSpeedPercent * 255U / 100U;
  if (duty > 255U) duty = 255U;
  return duty;
}

static void sawBldcPwmApply() {
  if (!sawState) {
    digitalWrite(SAW_MOSFET_PIN, LOW);
    sawBldcForceLow();
    return;
  }
  digitalWrite(SAW_MOSFET_PIN, HIGH);
  const uint32_t duty = sawSpeedDuty();
  if (duty == 0U) {
    sawBldcForceLow();
    return;
  }
  sawBldcApplyDuty(duty);
}

static void sawBldcPwmSetpointOnly() {
  if (!sawState) return;
  digitalWrite(SAW_MOSFET_PIN, HIGH);
  const uint32_t duty = sawSpeedDuty();
  if (duty == 0U) {
    sawBldcForceLow();
    return;
  }
  sawBldcApplyDuty(duty);
}

void setMag(bool on) {
  magState = on;
  digitalWrite(MAG_PIN, on ? HIGH : LOW);
  magOnSinceMs = on ? millis() : 0;
}

void setVac(bool on) {
  vacState = on;
  digitalWrite(VAC_PIN, on ? HIGH : LOW);
}

void setSaw(bool on) {
  sawState = on;
  sawBldcPwmApply();
}

int readAdcAvg(int pin, int samples = 16) {
  long acc = 0;
  for (int i = 0; i < samples; i++) {
    acc += analogRead(pin);
    delayMicroseconds(50);
  }
  return (int)(acc / samples);
}

float adcVoltageFromRaw(int raw) {
  return (float)raw / 4095.0f * TOOL_VCC;
}

float computeToolRFromVoltage(float vTap) {
  if (vTap <= 0.01f || vTap >= TOOL_VCC - 0.01f) return 0.0f;
  return vTap * TOOL_R_SERIES_OHMS / (TOOL_VCC - vTap);
}

/** 1=2.2k, 2=5k, 3=10k, 0=unknown */
int classifyToolOhms(float r) {
  if (r < 500.0f) return 0;
  int best = 0;
  float bestErr = 1e9f;
  for (int i = 0; i < 3; i++) {
    float err = fabsf(r - (float)TOOL_NOMINAL_OHMS[i]);
    if (err < bestErr) {
      bestErr = err;
      best = i + 1;
    }
  }
  if (bestErr > 1500.0f) return 0;
  return best;
}

float readCompressionMm() {
  int raw = readAdcAvg(POT_ADC_PIN);
  float compression = (float)(POT_RAW_FREE - raw) / 4095.0f * POT_STROKE_MM;
  if (compression < 0.0f) compression = 0.0f;
  return compression;
}

void readToolId(float &rOut, int &idOut) {
  int raw = readAdcAvg(TOOL_ID_ADC_PIN);
  float v = adcVoltageFromRaw(raw);
  rOut = computeToolRFromVoltage(v);
  idOut = classifyToolOhms(rOut);
}

void sendAck(const String &msg) {
  MainSerial.println(msg);
  Serial.println(msg);
}

/** Full tool line for main UI / mstatus (same shape as MOSFET board). */
void sendMosfetStyleStatus() {
  float rTool = 0;
  int toolId = 0;
  readToolId(rTool, toolId);
  float compMm = readCompressionMm();

  String msg = "STATUS MAG=" + String(magState ? "ON" : "OFF") +
               " VAC=" + String(vacState ? "ON" : "OFF") +
               " SAW=" + String(sawState ? "ON" : "OFF") +
               " SAW_SPD=" + String((int)sawSpeedPercent) +
               " TOOL_R=" + String(rTool, 0) +
               " TOOL_ID=" + String(toolId) +
               " COMP_MM=" + String(compMm, 2);
  MainSerial.println(msg);
  Serial.println(msg);
}

// Limit switches (wired to GND)
// Stage 1 turntable: CW-only limit (sensor D13). S1=1 when active (blocks s1cw on main).
const int STAGE1_CW_LIMIT_PIN = 13;

const int STAGE3_LIMIT_PIN = 32;
const int STAGE2_LIMIT_PIN = 33;
const int STAGE4_LIMIT_PIN = 25;
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

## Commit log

2026-04-07 corrected mosfet ovewritten file
    [main.cpp, mosfet_board.ino]
2026-04-07 added new stepper driver, sequential commmand suppport, parallel command support, and configured missing motors
    [main.cpp]
2026-04-08 reordered stages, combined s2 motors for manual control, cleaned up app ui
2026-04-09 resolved motor directions
2026-04-10 ros stuff
    [104t_ringpulley.stl, 42t_pulley.stl, 48t_pulley.stl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]
2026-04-12 new ramses bridge - untested
    [py_config_cmds.txt]
2026-04-12 added tool control and resolved merge conflicts
    [app.js, main.cpp, mosfet_board.ino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]
2026-04-12 arm rviz sim syncing working
    [104t_ringpulley.stl, 42t_pulley.stl, 48t_pulley.stl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]
2026-04-12 Web UI lift autohome, vertical pose, and firmware homing improvements
    - Add one-click lift routine with syncabs, staged homes, bounce homing, final
    vertical move, and setpos zero at vertical; Go to vertical button and
    VERTICAL_POSE constant.
    - Wait on firmware DONE/ERR for syncabs, homes, and setpos; extend home 2–4
    flow with the same completion handling.
    - Firmware: S1 limit homing with mid-chunk limit recovery for S2–S4; home s1
    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
2026-04-12 calibrating zeroes, added IK initial
2026-04-13 updated zeroing, autohoming, and sensors
2026-04-13 feat: web sequence motion options, S5 homing pre-jog, pose JSON
    - Firmware: jog C5 250 steps (c5r sense) before S5 Hall seek (straight and bounce).
    - Web app: per-pose maxSps/ramp for saved sequences; bounce-home steps in sequences;
    limit autohome final syncabs uses half maxSps; UI hints updated (app + data copies).
    - Poses: add me424-saw-truw-zero.json and saw-grab-true-zero.json.
    Made-with: Cursor
2026-04-17 fixed bugs related to flashing
    [main.cpp]
2026-04-20 moved boards
2026-04-30 add code appendix for final report
    Includes landscape 2-column appendix with tight formatting in docs/, new pose JSON files, wokwi simulation setup, and latest updates to src/main_board/main.cpp.
    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
    [main.cpp]
2026-04-30 revert appendix to simple tight formatting version
    Removed landscape/columns to avoid complexity; tightened font/spacing in docs/code_appendix_simple.tex.
    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
